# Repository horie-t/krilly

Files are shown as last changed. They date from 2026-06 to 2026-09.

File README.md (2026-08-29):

# krilly

Krilly はオムニホイールを備えたマイクロマウスです。Raspberry Pi 5 上で動作する
**ホロノミック（3輪オムニ・kiwi ドライブ）** マイクロマウスで、クラシック 16×16
マイクロマウス競技への出場を目標としています。

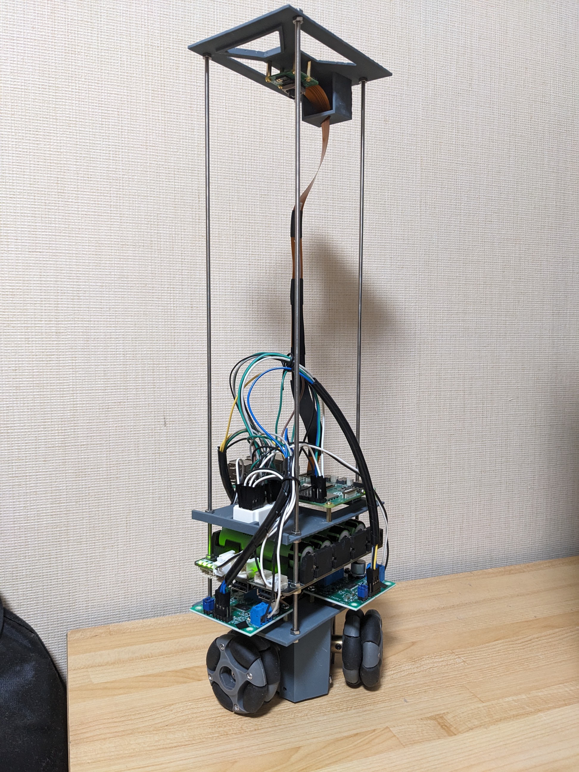
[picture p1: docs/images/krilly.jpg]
krilly


https://github.com/user-attachments/assets/f9e897da-61f6-41a8-bfa9-4333550319e2

## ハードウェア

- Raspberry Pi 5
- オムニホイール 3個（Ø48 mm・幅 25.5 mm）
- ステッピングモーター 3個（ステップ角 1.8°）＋ L6470 ドライバ 3個（SPI デイジーチェーン）
- BNO055 9軸センサー（UART モード）
- Raspberry Pi カメラモジュール V3（広角）— 下向きに取り付け、迷路の**赤い壁上面**を検知

## アーキテクチャ

下位 → 上位のレイヤ構成（`src/krilly/` を参照）:

| レイヤ | 役割 |
|---|---|
| `hal` | L6470（SPI）/ BNO055（UART）/ カメラ（picamera2） |
| `kinematics` | kiwi ドライブの正逆運動学、輪速 ⇄ ステップレート変換 |
| `motion` | ボディ速度 (vx, vy, ω) → 3輪、加減速ランプ |
| `localization` | デッドレコニング + ジャイロ姿勢 + カメラ格子補正 `[X, Y, φ]` |
| `perception` | 赤い壁上面の検出（HSV） |
| `solver` | 迷路モデル（16×16・共有エッジ）+ flood-fill + 最短経路 |
| `strategy` / `app` | 探索ラン / 最速ランの状態機械 |
| `config` | 車体・迷路の寸法（YAML） |

車体座標系・ホイール(モーター)番号・BNO055 取り付け向きの定義は
[`docs/coordinate-frames.md`](docs/coordinate-frames.md) を参照。

## 開発

```bash
python3 -m venv --system-site-packages .venv
source .venv/bin/activate
pip install -e ".[dev]"
pytest
```

Raspberry Pi 5 の実機セットアップは [`docs/setup-pi5.md`](docs/setup-pi5.md) を参照してください。
競技会場で走らせる当日の手順は [`docs/venue-checklist.md`](docs/venue-checklist.md) にあります。

進捗は [GitHub Project ボード](https://github.com/users/horie-t/projects/4) で
Milestone（M0〜M6）と Issue により管理し、コードはレビュー済みの PR を通じてマージします。

## ライセンス

MIT — [LICENSE](LICENSE) を参照。

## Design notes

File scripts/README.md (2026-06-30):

# scripts/

実機ブリングアップ・キャリブレーション・テレオペ用の単体スクリプト置き場。

各マイルストーンで追加予定:

- **M1**: `motor_spin.py`（L6470 単体/3輪回転）, `imu_stream.py`（BNO055 方位表示）, `red_detect.py`（カメラ赤検出オーバーレイ）
- **M2**: `teleop.py`（キーボード→速度指令）, `calibrate.py`（距離・L 補正）

スクリプトは `python -m` で実行できるよう、パッケージ機能を薄く呼び出す形にする。

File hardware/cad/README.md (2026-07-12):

# hardware/cad/

筐体（シャーシ）の **FreeCAD** 設計ファイル置き場。

## 方針
- 設計本体の **`*.FCStd`** をコミットする（例: `krilly-chassis.FCStd`）。
- バックアップ・一時ファイル（`*.FCStd1`, `*.FCBak`, ロックファイル）は
  `.gitignore` 済み。
- 書き出した中間データ（STL/STEP 等）は [`export/`](export/) に置く。

## 規約
- 単位は **mm**。
- 座標系は [`docs/coordinate-frames.md`](../../docs/coordinate-frames.md) に準拠
  （**+x 前 / +y 左 / +z 上**、原点は車体中心）。ホイール位置・モーター番号
  （M0 前方 / M1 後左 / M2 後右）もこの図に合わせる。
- 主要寸法（ホイール Ø48mm・幅25.5mm、中心↔接地点 `L` など）は
  `src/krilly/config/robot.yaml` と整合させる。

## 注意
- `.FCStd` はバイナリ（zip 形式）なので Git 上で差分は取りにくい。ファイルが
  大きくなる/版が増える場合は Git LFS の導入を検討する。

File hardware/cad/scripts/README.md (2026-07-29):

# hardware/cad/scripts/

`../*.FCStd` から図面などを生成するスクリプト置き場。FreeCAD の**コンソール版**で
動かすので GUI は不要。

## 実行

```bash
hardware/cad/scripts/fcrun hardware/cad/scripts/three_view.py
```

[`fcrun`](fcrun) が使える中で最も新しい FreeCAD を自動で選ぶ。優先順位:

| 順 | 対象 | 備考 |
|---|---|---|
| 1 | `$FREECAD_CMD` | 明示指定 |
| 2 | `~/opt/FreeCAD-*/AppRun` | AppImage を展開した場合 |
| 3 | `~/opt/FreeCAD*.AppImage` | **推奨**。ネイティブパスで動く |
| 4 | Windows 側 `freecadcmd.exe` | WSL interop 経由。`wslpath` で変換 |
| 5 | PATH の `freecadcmd` | apt 版。Ubuntu 24.04 は 0.21.2 止まり |

## スクリプト

- [`three_view.py`](three_view.py) — 3部品の**三面図**（第三角法・A4横・尺度 1:1）を
  [`../export/`](../export/) に出力する。対象は `PARTS`、構成は `LAYOUTS` で定義。
  TechDraw の HLR で稜線とシルエットを抽出し、SVG は自前で組んでいる。

### 図の構成（2種を併置）

平面図と真下の立面図は紙面の**横軸**を共有し、その立面図と右隣の図は**縦軸**を
共有する。この整列規則が平面図の前後向きを一意に決めてしまうので、「平面図の前方を
どちらに向けるか」は主投影図の選び方と同義になる。第一角法にしても各図の像の向きは
変わらない（配置だけが変わる）ので、どちらかを選ぶしかない。

| 出力 | 平面図の前方 | 主投影図 | 用途 |
|---|---|---|---|
| `<部品>-3view.svg` | **紙面上** | 背面図（−x 視点） | [`krilly-frame.svg`](../../docs/images/) と読み合わせる |
| `<部品>-3view-side.svg` | **紙面右** | 側面図（−y 視点） | 車両の一般配置図の慣例。正面図が入る |

```
layout "b"                          layout "side"
[ 平面図 上=+x 右=−y ]              [ 平面図 上=+y 右=+x ]
[ 背面図 上=+z 右=−y ][ 側面図 ]     [ 側面図 上=+z 右=+x ][ 正面図 ]
```

`b` は平面図の前方を上に固定した結果、整列できる立面図が −x 視点だけになるため
正面図を含められない。正面図が必要なときは `side` を使う。

用紙は**尺度 1:1 のまま収まる最小のもの**を自動で選ぶ（A4横 → A3横）。選んだ用紙は
表題欄に出る。剛性強化版の chassis（111.5 × 81.1 × 56）は平面図を上向きにする構成
だけ A4 に収まらず A3横になる。

`THREE_VIEW_PARTS` 環境変数に部品名をカンマ区切りで渡すと対象を絞れる。

```bash
THREE_VIEW_PARTS=krilly-chassis hardware/cad/scripts/fcrun hardware/cad/scripts/three_view.py
```

スクリプトは以下を assert で自己検査する。

- 各図の `right` / `up` が実際に紙面の右 / 上に落ちているか
- 平面図と真下の立面図が横軸を、立面図どうしが縦軸を共有しているか
- 第三角法になっているか（平面図は elev1 の +up 側、右隣の図は +right 側の視点か）
- 図と注記・表題欄がページ内に収まり、重なっていないか

## 注意

- **`.FCStd` を書き戻さない。** スクリプトは `recompute()` / `save()` を呼ばない。
  FCStd は FreeCAD 1.1.0 (Windows) で作られており、古い版で保存すると壊れる。
  形状は保存済みの BREP をそのまま使えば正しく読める。
- **Windows 版で実行する場合の既定値に注意。** Python の既定エンコーディングが
  **cp932**、改行が **CRLF** になる。ファイルを書くときは
  `io.open(..., encoding="utf-8", newline="\n")` と明示すること（明示しないと
  図面中の日本語が文字化けする）。
- **軸のずれがある FCStd を描くとき**は [`three_view.py`](three_view.py) の
  `MODEL_TO_BODY_DEG` に Z 回りの補正角を入れる。`krilly-chassis.FCStd` は
  2026-07-25 に `Body.Placement` の Yaw=90 で車体座標系に揃えたので現在は `0`。

## 部品の組み付け位置 (2026-07-29 剛性強化版で実測)

各部品の `Body.Placement` を下表にすると、3部品が車体座標系で正しく積み重なる。
**3部品は共通の Ø3.4×4**（chassis の `(−41.55, ±35.05)`, `(47.95, −19.95)`,
`(47.95, 35.05)`）で締結される。この4穴の一致から XY を、干渉計算から Z を決めた。

| 部品 | Position (x, y, z) | Angle | 車体座標系での占有範囲 (X / Y / Z) |
|---|---|---|---|
| `krilly-chassis` | (0, 0, 0) | **Yaw 90°** | −55.550〜55.950 / ±40.550 / 0〜56.000 |
| `krilly-middle-plate` | (**0.400**, **0**, **58.500**) | **Yaw −90°** | −55.550〜55.950 / −55.550〜40.550 / 56.000〜64.000 |
| `krilly-roof` | (**−53.550**, **−38.550**, **64.000**) | 0° | −55.550〜55.950 / ±40.550 / 61.500〜65.500 |

全体で 111.500 × 96.100 × 65.500。middle-plate だけ −y 側に 15mm 張り出す非対称形状。

検証済み（2026-07-29）:

- 4穴の一致残差 **middle-plate / roof ともに最大 0.0000 mm**。他の回転角
  (0°/90°/180°) では 16〜87mm ずれるので回転は一意に決まる
- Z は接触かつ干渉ゼロになる値。middle-plate は 58.4 で干渉 67.4 / **58.5 で 0**
  / 58.6 で 0.1mm 浮き。roof は 63.9 で干渉 1.48 / **64.0 で 0** / 64.1 で浮き
- chassis↔plate と plate↔roof は**面接触**（干渉 0・最短距離 0）、
  roof↔chassis は 5.5mm クリアランス
- **3部品の X 範囲が −55.550〜55.950 で完全一致** — 位置合わせの裏付け
- `export/*.stl` は3部品とも**配置込み**で書き出され、FCStd の bbox と一致

### chassis の向きの根拠

Ø3.5 のモーター取付穴を軸方向でグループ化すると、軸が半径方向のものが3組あり
（穴位置はすべて半径 32.68）、各組が station 角を挟む。

| 軸方向 | 穴位置の角度 | station |
|---|---|---|
| ±x | +28.3° / −28.3° | **0°** = M0 前方中央 |
| 120° | 148.3° / 91.7° | **120°** = M1 後左 |
| 60° | 268.3° / 211.7° | **240°** = M2 後右 |

`docs/coordinate-frames.md` の 0°/120°/240° に一致するので `Yaw 90` が正しい。
剛性強化版は左右対称でなくなった（Y=0 鏡像の残差 8081）ため、対称性からは
向きを決められない。モーター取付穴の軸方向で判定すること。

## 環境の確認結果 (2026-07-25)

- Ubuntu 24.04 の apt 候補は `freecad 2:0.21.2` が上限。1.1.0 は入らない。
- 公式 Linux AppImage `FreeCAD_1.1.0-Linux-x86_64-py311.AppImage`
  (820.7MB, SHA256 `ef85f171…`) は `libfuse3` のみの環境でも直接実行できた。
- AppImage と Windows 1.1.0 の出力は**バイト単位で一致**。0.21.2 の出力とも
  ジオメトリは一致した（0.21.2 で出る `App::Point` 読み込み警告は datum point
  のみの欠落で、ソリッド形状には影響しない）。

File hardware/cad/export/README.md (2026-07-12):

# hardware/cad/export/

`hardware/cad/*.FCStd` から書き出した **STL / STEP** 等の共有データ置き場。

## 方針
- ファイル名は元の部品名に合わせる（例: `krilly-chassis.stl`, `krilly-chassis.step`）。
- STL は 3D プリント用。単位は **mm**、座標系は元の FreeCAD ファイルに準拠
  （[`docs/coordinate-frames.md`](../../../docs/coordinate-frames.md): +x前 / +y左 / +z上）。
- STEP は他 CAD との受け渡し用。
- これらは `.FCStd` から**再生成できる派生物**なので、更新時は元ファイルも
  必ず一緒にコミットすること。

## 3Dプリンタ設定

対象機は ELEGOO Mars 2 での印刷の設定。ELEGOO 光造形3Dプリンター用 水洗い樹脂 UVレジンを使用。

* レイヤーの高さ: 0.05mm
* 初期層の数: 10
* 露光時間: 5s
* 初期層の露光時間: 150s
* 消灯遅延: 7s
* 初期層消灯遅延: 8s
* 初期層リフト距離: 5mm
* リフト高さ: 5mm
* 初期層上昇速度: 30mm/s
* 上昇速度: 50mm/s
* リトラクト速度: 150mm/s

## 注意
- STL/STEP はバイナリで大きくなりやすい。版が増える場合は Git LFS を検討する。

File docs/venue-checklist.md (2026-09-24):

# 会場での走行手順 (issue #78)

競技会場で走らせる当日の手順。**練習室と会場で変わるのは照明と床**で、そのどちらも
カメラの壁判定に直接効く。ここに書いてあることは全部、実機で測った結果に基づく
(根拠は CLAUDE.md の該当項目を参照)。

判断に使う数字は 2 つだけ:

- **暗さへの余力 [段]** — 起動直後の 1 行に出る。走らせる前の判断に使う
- **余裕倍率** — 一番弱い壁 ÷ しきい値。走った後の判断に使う (`survey_report`)

---

## 走らせる前

### 1. バッテリ残量を **LED で** 確かめる (電圧計では分からない)

電源は Geekworm X-UPS1 (18650 x4)。**L6470 の VS も Pi もここから取っている**
(12V/3A と 5V/3A は別々の上限)。基板の緑 LED 4 個が 25 / 50 / 75 / 100 % を示す。

**LED 4 つ (満充電) で始めること。** 効くのは**開始時の充電状態だけ**で、
5 走のセッションは弱ったパックを炙り出す負荷ケースになる。

**電圧を測っても残量は分からない。** X-UPS1 の 12V 出力は**安定化されている**ので、
電池が満充電でも半分でもほぼ 12V を返し、保てなくなったところで落ちる。
ここには以前「満充電で 12.17V」と書いてあったが、それは電池ではなく
**レギュレータの出力**を測っていた。「204 秒のセッションで 12.17 → 12.18V と
ほとんど下がらない」という測定結果自体が、安定化されている証拠になっている
(生のリチウムパックをモーターで 204 秒引いて下がらないということはない)。

**残量をソフトから読む手段は無い。** I2C の残量計は載っておらず、基板が出しているのは
LBAT (セル電圧 ≤ 3.0V で High) と PLD (外部電源断) の GPIO だけ。**LBAT は遅すぎる** —
リチウムセルの 3.0V はほぼ空で、滑りはそのずっと手前から始まる。目視の LED が指標。

弱ったパックは滑る。**L6470 のフォールトは出ず** (BEMF の脱調検出はこの速度では鈍い)、
**残差も出ない** (odometry は指令速度を積分するので、滑っても推定は理想どおり進む)。
つまり**ログを見ても分からない**。気づく手段は 2 つだけ:

1. **走らせる前に LED を見る** ← 確実
2. **異音を聞く** — 走行中に届く唯一の症状。ただし**擦れる音の原因は 4 つあって、
   パックはその 1 つに過ぎない。**

   ここには以前「#87 の測定で実際に起きた」例を挙げていたが、**あの帰属は誤りだった**:
   異音 + 進行方向に 27mm 足りない + 残差 0.4mm は事実だが、**パックは 12.17V で満充電**で、
   操作者も接触を見ていない。真の原因は**床板 (市販の競技用床) の撓みが機体底に接触**して
   いたことで、バッテリ位置を下げ・スペーサーを増やして解決した。
   **この 1 つの事象が「壁を擦った」→「電池が弱った」→「床板」と 3 回診断し直されている。**
   だから**「前にも聞いた音だ」で決めないこと。**

### 擦れる音がしたときの切り分け順

1. **LED を見る** — 4 つ点いていれば電源ではない
2. **接触を見ていたか** — 操作者が見ていて壁に触っていなければ、擦ったのではない
3. **前進と後退を聴き比べる** — `cell_move_demo --seq F4` と `--seq B4`。前進と後退は
   **同じ 2 輪を同じ輪速で回す** (W1 355 / W2 344 step/s、符号が反転するだけ) ので、
   **片方向だけ鳴るなら電源でもトルクでもなく機械**。#103 はこれで見つかった —
   ローラーのゴムが芯より長く、軸方向に押されるとホイールのプレートに擦れていた。
   机上の判定は**手でローラーを片側に寄せて回す** (= ホイールが進行方向に対して斜めの状態)
   — 固ければそれ
4. **床で切り分ける** — 黒い床で鳴って木の床で鳴らないなら、板の撓み

4 原因の対照表は CLAUDE.md の「An audible rub has had four different causes」。

### 2. 迷路の周囲 1 セルぶんを片付ける

960x720 では画角が **3.15 x 2.33 セル**あり、迷路の外に置いた赤いものが写る。
実際に、迷路の東に置いた赤い定規袋が `right:right` に 0.97 と出て、
その場所で軸角の補正が棄却された。

### 3. スタートセルに置いて、会場の照明の下で起動する

**露出と AWB は起動 0.5 秒後にロックされる。** つまり 1 回の走行は「起動した瞬間の光」に
焼き付けられる。

- 廊下で起動して運び込むのは、**別の光でロックすること**になる
- 起動の瞬間に人が機体の上に影を落とすと、1 走行まるごと狂う
- 照明が変わったら、撮り直しではなく**スクリプトの再起動**が要る

### カメラを外した・付け直したら (会場に向かう前に)

配線の変更などでカメラを付け直すと、**傾きが同じでも高さが数 mm 変わり、位置補正の校正がずれる**
(2026-09-24: ケーブルの取り回しを変えてカメラが 5-7mm 高くなった)。壁の有無は読めてしまうので
気づきにくい。四方に壁のあるセルに**定規で中央に**置いて:

```bash
python -m scripts.wall_detect --measure 5 --ev -2     # 向かい合う壁の読み (前と後、左と右) の差を見る
```

差が **2mm を超えたら** `python -m scripts.camera_fov --full-only --emit-bands --ev -2` で
`CALIBRATED_BANDS` を測り直す (手順は CLAUDE.md の該当項)。

### 4. ネットワーク (前日の試走会で SSH するとき)

スマートフォンのテザリング `AndroidAP135XL` に Pi とノート PC をつなぐ。設定と理由は
`docs/setup-pi5.md` の 8 節。

1. Pixel のテザリングをオンにする (「自動的にオフにする」は無効のまま)
2. Pi の電源を入れる。テザリングが見えれば自動でそちらにつながる (優先度 10、家の Wi-Fi は 0)
3. ノート PC も `AndroidAP135XL` につなぎ、WSL で `krilly` (`krilly.local` を Windows に引かせて SSH)
4. **つながらなければシリアル**: USB-TTL をピン 6 / 8 / 10 に挿し、PuTTY (115200、フロー制御 None) で
   ログインして次を見る

```bash
nmcli -t -f DEVICE,CONNECTION device        # wlan0:AndroidAP135XL になっているか
nmcli device wifi list                      # テザリングが見えているか (SSID の綴り)
sudo nmcli connection up AndroidAP135XL     # 手でつなぐ
hostname -I                                 # IP を読んで ssh tetsuya@<IP>
```

**USB-TTL アダプタとジャンパ線は必ず持っていく。** テザリングの IP は入れ直すたびに変わりうるので、
IP を書き留めて使い回さないこと。

### 5. 当日はボタンで走らせる (#79)

会場ではネットワーク越しに操作できないので、**前日の試走で走らせて良かったコマンドを
保存しておき、当日はボタンで走らせる**。

**前日 (試走会、SSH できるうちに)**:

```bash
sudo systemctl stop krilly-launcher          # GPIO を取り合うので止めておく
python -m scripts.speed_run --size 16 --ev -2 --white-tops --save-run-config
python -m scripts.launcher --check           # 当日走るコマンドを表示する
sudo systemctl start krilly-launcher
```

`--save-run-config` は**完走したときだけ**書く (中断したコマンドは保存されない)。
`--check` の出力で **EV と `--white-tops`** を必ず見ること — 木の床 (EV 0) の設定を
黒い床へ持ち越すと、後方の壁を見落とす (#100)。

**当日**:

| 操作 | 音 | 意味 |
|---|---|---|
| 電源を入れる | ピッ | 起動した (設定が読めないと **ピピピピピ**、そのときは走れない) |
| 1 秒押して離す | ピッ (1 秒) → ピッ ピッ ピッ ピー | 3 秒後に発進。**カウントダウンの間に手を機体の上からどける** (露出と AWB は走行プロセスの起動時にロックされる。影が落ちると 1 走行まるごと狂う) |
| カウントダウン中に押す | ピピ | 取り消し |
| 走行中に押す | ピー | 停止 (Ctrl-C と同じ経路) |
| — | ピピピッ | 完走 |
| — | ピー ピー | 中断 (安全チェックが止めた等) |
| — | ピピピピピ (繰り返し) | **走行プロセスが止まらない。VS 遮断のトグルでモータを止める** |
| 待機中に 5 秒押し続ける | ピー (1 秒) | 電源を切る (SD カードを守る) |

走行ごとの出力は `logs/run_<日時>.log` に残る。

---

## 起動直後の 1 行を読む

```
露出をロック: 32.7ms (フレーム間隔の上限) / ゲイン 3.51 (上限 16.0、残り 2.2 段)
```

**「残り N 段」が暗さへの余力**。1 段 = 明るさが半分になっても保てるという意味。
露出は 30fps 固定で頭打ちになるので、暗さに対抗しているのは実質ゲインだけ
(実測: 調光 100/30/5% で露出は 32.7ms のまま、ゲインが 2.16 → 6.21 → 10.67)。

| 残り | 判断 |
|---|---|
| **2 段以上** | 余裕。そのまま走らせる |
| **1〜2 段** | 走らせてよい。走行後に `survey_report` で余裕倍率を確認する |
| **1 段未満** | 警告が出る。下の手順へ |

### 警告が出たら: `--max-frame-duration 100` を付けて再起動する

```bash
python -m scripts.speed_run --size 16 --max-frame-duration 100
```

露出の上限が 33.3ms から伸び、**0.6 段ぶん**暗さに強くなる (実測: 露出 32.7 → 50.0ms、
ゲイン 3.51 → 2.29)。代償は 1 停止あたりの待ち時間だけ — 壁の撮影は必ず停止中に
行われる (移動 → 惰行 → 撮影) ので、走行中のブレは判定に入らない。

**100 より大きい値に意味は無い。** libcamera の AE が 50ms で露出を打ち切り、
その先はゲインに回すため、200 でも 400 でも結果は同じだった。

### それでも警告が出るなら

設定でできることは終わり。**照明が足りない。**

1. 運営に照明を上げられないか相談する
2. 上げられないなら、その照度で走ることを覚悟したうえで、まず
   **`--dry-run` か `wall_detect --measure 5`** で赤割合を見る (走らせずに確認できる)
3. 弱い壁が 0.20 を割っているようなら、走らせれば壁を倒す公算が高い

> **しきい値を下げて凌ごうとしないこと。** 進路チェックが同時に鈍り、
> 「壁検出をすり抜けたものを進路確認が拾う」という二重の防護が一重になる。
> #88 で実際にそれが起き、本物の壁 0.24 が検出 (0.25) と進路確認の両方を
> 0.01 差ですり抜けて壁を突き破った。

---

## 黒い床では `--ev -1` を付ける

**会場の床は黒い。** 視野の大半が黒いと AE が開き (ゲイン 3.3 → 7.1)、**後方の壁の帯だけが
淡くなって彩度が `s_min` を割る**。実測 (#100、市販の競技用床): back の赤割合が
**0.46 → 0.13** — しきい値 0.08 の 1.6 倍しかなく、#88 で壁を突き破ったときの 0.24 より低い。
front / left / right は 0.40-0.45 のまま変わらないので、**back だけを見ること**。

対策は **`--ev -2`** (AE の目標を 2 段下げる)。露出時間の決め打ちと違い、会場の明るさに追従する。

廊下の東端 (悪い方) での実測:

| | ゲイン | back | 帯の彩度 |
|---|---|---|---|
| EV 0 | 8.33 | **0.09** | S 42 (帯の 80% が s_min 割れ) |
| EV -1 | 3.94 | **0.17** | S 42 (69%) |
| **EV -2** | 2.00 | **0.53** | S 64 (26%) |

**EV -1 では足りない。** 西端では 0.48 まで戻るが、東端では 0.17 止まりで、
しきい値 0.08 の 2 倍しかない。-2 まで下げて初めて 0.53 (6.6 倍) になる。

front / right は EV をいくつにしても 0.42-0.46 で動かない (明度は下がるが彩度が
上がるため)。**下げて失うものは無く、back の余裕だけが戻る。**

**ただし -3 以下にはしないこと。** EV -2 の時点で back の帯の 20% が既に `v_min=40` を
割っている (EV -1 では 0%)。s_min の崖と v_min の崖の間で、-2 がその真ん中。

`--ae-constraint Highlight` は効かない (0.5 段しか戻さず back は 0.11 のまま)。

**どの辺が弱くなるかは照明の位置で決まる。** 機体の後ろの壁が天井灯を鏡面反射する
角度に来るので、この部屋では back だった。会場では別の辺かもしれないので、
**4 辺すべてを見て、一番低い辺で判断すること。**

### 手順

1. `--measure 5` を素で撮り、**4 辺の中で一番低い赤割合**を見る
2. 0.30 以上 → そのままでよい
3. 0.30 未満 → `--ev -1` で再測定 → まだ低ければ `--ev -2`
4. `--ev -2` でも戻らなければ、帯が淡いのではなく**暗すぎる**可能性がある
   (ゲインの残り段数を見る)。その場合は EV を戻して `--max-frame-duration 100`

## 黒い床では `--white-tops` も付ける (#125)

競技規定 2-1 で、**始点の区画と終点領域の区画の壁の上面は赤・白・黄のどれでもよい**。
赤しか見ないと、ゴールの境界の壁 7 枚が全部「開」と読まれ、最初にゴールへ近づいたときに
白い壁へ突っ込む。進路確認も「見えた壁で止まる」検査なので、見えない壁は止められない。

`--white-tops` で白・黄の帯も壁として読む。**`--ev -2` と組で付ける** (どちらも黒い床の設定)。

```bash
python -m scripts.speed_run --size 16 --ev -2 --white-tops
```

- **木の床では付けないこと。** EV -2 では木の床が全面「黄」と判定される (実測)
- 白・黄の帯は**壁の有無と進路確認にだけ**使い、位置補正には使わない。始点・終点では
  その軸の位置補正が効かないだけで、走行は続く
- `wall_detect --measure 5 --ev -2 --white-tops` の出力で、白・黄で拾った辺には `w` が付く
- `--white-tops` を付けると**始点の 3 壁 (前以外) を規定 2-3 から地図に書き込む** (#126)。
  始点が規定の形でない自宅の盤面 (excerpt8 系・twisty8) で黒い床を使うときは `--no-seed-start`

**試走で確かめること** (会場でしか分からない): 本物の始点・終点の上面が白か黄か、
どの辺がそうか、その明るさ。探索ランを `--save-frames` 付きで 1 本走らせれば全部撮れる。
手元の実測は**白・黄 0.446 以上に対して壁なし 0.002 以下** (しきい値 0.08)。**白の彩度は
ホワイトバランスのロックで動く** (同じ白い壁が S 6-39 のことも S 64-73 のこともあった)。会場の白が
つや消しか光沢か、床の光沢がどこに出るかで変わりうるので、`w` の付いた辺の値を見ること。

## ちらつきの確認 (水銀灯の会場では必須)

体育館の水銀灯は 100/120Hz で明滅する。露出は固定なので、フレームによって
明るさが変わりうる。**静止しているのに値が動けばそれ**:

```bash
python -m scripts.wall_detect --measure 5
```

「静止中のばらつき」の幅が 0.0mm から動くか、赤割合がフレーム間で振れるかを見る。
練習室の LED (NLEH08002E-LC) では幅 0.00 / 軸角のばらつき 0.086° で、ちらつきは無かった。
**会場でちらついたら**、露出時間を 1/50 秒の整数倍 (10ms / 20ms) に固定するのが対策
(現状そのオプションは無いので、その場では `--max-frame-duration` で露出を動かして
振れが減る点を探すことになる)。

---

## 走った後に読む

会場の迷路は形が未知なので `--truth-maze` は使えない。ラベルは走行後に確定した
地図から貼られる:

```bash
python -m scripts.search_run --size 16 --save-frames survey/venue/run
python -m scripts.survey_report survey/venue/run_labels.csv --sweep
```

**読むのは誤判定の数ではなく余裕倍率。** 学習地図で貼ったラベルでは
「毎回見落としている壁」が壁なしと記録され、誤判定 0 に見えてしまう。

| 余裕倍率 | 意味 |
|---|---|
| **5 倍前後** | 練習室と同じ。健全 |
| **2〜3 倍** | 走れるが、壁が 1 枚傾いただけで落ちうる |
| **1.5 倍以下** | 危険。#23 では誤判定 0 のまま 1.4 倍まで落ちていた |

### 余裕が足りないと分かったら

**触るのはしきい値ではなくマスク。** 保存したフレームに対して、追加の走行なしで
その場で決められる:

```bash
python -m scripts.wall_detect --batch survey/venue --weak 5      # なぜ弱いのか (色相? 彩度?)
python -m scripts.wall_detect --batch survey/venue --h2-lo 120    # 変えたらどうなるか
```

`--weak` が「取りこぼしの主因」を名指しする。`--batch` を色相や彩度を振りながら回し、
**壁側だけが上がり壁なし側が動かない**範囲を探す。壁なし側も一緒に上がるなら、
それは壁ではない何かを拾い始めている。

実際にこの手順で `h2_lo` を 140 → 125 に直した (所要 10 分、走行は確認の 1 回だけ)。
そのとき一番淡い壁は 6500K の明るい照明下で **0.046** — しきい値 0.08 を下回っており、
**見落とし = 衝突**だった。

---

## 走行中

- **ボタンで起動したときは、止めるのもボタン** (押した瞬間に SIGINT)。止まらなければ
  **VS 遮断のトグル**。SSH から走らせたときは Ctrl-C
- **止めるのは Ctrl-C。ESC は効かない** (これらのスクリプトはキー入力を読まない)。
  強制終了してモーターが回り続けたら `python -m scripts.motor_stop`
- 走行中止を自分から申し出ると、**規定 3-5 により迷路の記憶を全消去**した場合にのみ
  認められる (異常が審判に明らかな場合を除く)。赤割合 0.09 での安全停止は
  「あきらかに走行に異常」とは読まれない公算があり、そのとき探索は失われる。
  一方、規定 3-1 では記録は**最速の 1 走行**なので、最速ランが時間切れになっても
  失うのは時間だけ。**迷ったら止めずに走らせる**

---

## 参考

- 照明とカメラの実測値、赤マスクの根拠: CLAUDE.md の
  「Auto-exposure eats the brightness axis」「Wall detection is ROI-based」の項
- 校正データの取り方と読み方: CLAUDE.md「The search run *is* the survey」の項
- Pi の初期設定: [`setup-pi5.md`](setup-pi5.md)

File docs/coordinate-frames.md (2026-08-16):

# 座標系・車体・センサー・ホイールの定義

Krilly（3輪オムニ・ホロノミック）の**車体座標系**と、**ホイール/モーター番号**、
**BNO055 センサーの取り付け向き**の関係を定義する。運動学（M2 `kinematics/kiwi.py`）・
自己位置推定（M3）はすべてこの規約に従う。

車体・センサー・ホイール座標系

## 1. 車体座標系（body frame）

右手系。ROS REP-103 に準拠。

| 軸 | 向き |
|---|---|
| **+x** | 前方（ロボットの進行方向・正面） |
| **+y** | 左 |
| **+z** | 上（上面図では紙面手前） |
| **+ω** | +z 周りの回転 = **反時計回り(CCW) = 左旋回** |

- 角度はすべて **+x から反時計回り**に測る。
- 「前」は +x 方向。上面図では上を前として描く。

## 2. ホイール / モーター番号

各ホイールは**スポーク角（中心から見た位置角）**と**駆動方向角 θ（正回転で接地点が
進む向き）**を持つ。θ はスポーク角 + 90°（接線・CCW 向き）。
`config/robot.yaml` の `wheel_angles_deg` は**この駆動方向角 θ**である。

| 番号 | スポーク角(位置) | 駆動方向角 θ | 車体上の位置 |
|---|---|---|---|
| **M0 / W0** | 0° | **90°**  | 前方中央 |
| **M1 / W1** | 120° | **210°** | 後方左 |
| **M2 / W2** | 240° | **330°** | 後方右 |

- 左右対称：M1(後左) と M2(後右) は前後軸(+x)について鏡像。M0 は正面。
- **`config/robot.yaml` の `wheel_angles_deg` には「スポーク角」列 `[0, 120, 240]` を入れる**
  （運動学の式が θ にスポーク角を取るため。駆動方向 = スポーク角 + 90° = [90, 210, 330]）。
- 3輪とも正回転（正の速度）で接地点が CCW 接線方向（駆動方向）に進む → 車体は **+ω（左旋回）**。

## 3. 逆運動学プレビュー（M2 で実装）

ボディ速度 `(vx, vy, ω)` から各ホイールの周速 `v_i`（`θ_i` は**スポーク角** `[0,120,240]`）：

```
v_i = -sin(θ_i)·vx + cos(θ_i)·vy + L·ω
```
（`(-sinθ_i, cosθ_i)` は駆動方向 = スポーク角+90° の単位ベクトル）

- `L` = 中心から接地点までの距離（`config/robot.yaml` の `center_to_wheel_m`、要実測）。
- 例：純前進 `vx>0` → `v0=0, v1=-0.87vx, v2=+0.87vx`（前輪 M0 は前進に寄与せず後2輪が押す）。
- 例：純横移動 `vy>0` → `v0=+vy, v1=-0.5vy, v2=-0.5vy`。
- 例：純旋回 `ω>0` → `v0=v1=v2=L·ω`（3輪同速正回転で左旋回）。

周速 → ステッパ速度の変換は `kinematics/kiwi.py`（M2）で `wheel_speed_to_step_hz`
（L6470 Run 用の**フルステップ/s**）を用いる。

**前進と横移動では働く車輪が違う**（上の 2 例のとおり）。W0 のスポーク角はほぼ 0°、つまり
駆動方向が真横なので、W0 は事実上「横専用の車輪」で、前進中はほとんど回らない。帰結が 2 つ:

- 前進で校正した `wheel_diameter_m` は実質 W1/W2 の実効径で、W0 の径については何も
  言っていない。実測すると横だけ 1% 長かった（#76）。このため `robot.yaml` は
  `wheel_diameters_m: [d0, d1, d2]` で**輪ごとの実効径**を持てる。
- W0 のハブや軸の緩みは、前進の測定にはほぼ出ずに横移動と旋回だけを汚す（#72）。
  「前進は綺麗なのに横がばらつく」ときはまず W0 の締結を疑うこと。

## 3b. 走行時の車体の向き（旋回レス走行、M6 #76）

本機はホロノミックで、下向きカメラが 4 辺を同時に見るため、**探索・最速走行を通じて
車体の向きは迷路北に固定**し、進行方向の変更は「横移動への切り替え」で行う。

- 迷路方角 → 車体軸: **N=前(+x) / S=後(−x) / W=左(+y) / E=右(−y)**（φ=+π/2 固定）。
- `perception.wall_detect.body_walls_to_maze()` はこの固定写像に退化する。
- その場旋回のプリミティブは残してある（`--turn-in-place`）。退避路であると同時に、
  `gyro_scale_z` の校正手順（`cell_move_demo --seq L,L,L,L --camera-yaw`）が
  旋回に依存しているため。

## 4. モータードライバ（L6470）との対応

- **L6470 デバイス index i ＝ モーター Mi ＝ ホイール Wi**（i=0,1,2）。
- デイジーチェーン（`hal/l6470_chain.py`）は index0 が Pi の MOSI に最も近い配線
  （`mosi_is_index0=True`）。**M0→M1→M2 の順に SDO→次段SDI を繋ぐ**こと。
  逆順に配線した場合は `L6470Chain(..., mosi_is_index0=False)` で対応。

## 5. BNO055（9軸センサー）の取り付け向き

融合済みの絶対方位（heading/yaw）とジャイロを車体座標に一致させるため、
**センサー軸を車体軸に合わせて取り付ける**：

| BNO055 軸 | 合わせる車体軸 |
|---|---|
| X | +x（前方） |
| Y | +y（左） |
| Z | +z（上） |

- **heading(yaw) は Z 軸周り**の回転。上記取り付けなら、heading の増加方向が
  車体の **+ω（CCW=左旋回）と同符号**になる。
- ジャイロ **z 軸レート** が `+ω`（旋回角速度）に対応。M3 の姿勢推定はこれを主に使う。
- 物理的にこの向きに取り付けられない場合は、BNO055 の `AXIS_MAP_CONFIG` /
  `AXIS_MAP_SIGN` レジスタで軸を再マップする（現ドライバは未設定＝取り付けを
  合わせる前提）。

## 6. 前提・未確定事項（要確認）

- **前方/車輪角度**：✅ 実機で校正済み（#11）。`wheel_angles_deg` には**スポーク角**
  `[0,120,240]` を入れる（式が θ にスポーク角を取るため）。当初 config に駆動方向角
  `[90,210,330]` を入れていて並進が 90° ずれていたのを、`drive_demo` で
  +x=前進 / +y=左 / +ω=CCW になることを確認して修正済み。物理配置（M0 前・M1 後左・
  M2 後右）と本書の図は正しい。
- **`L`（center_to_wheel_m）**：現状 config は暫定値。M2 のキャリブレーションで確定。
- **BNO055 heading の実符号**：実機で `sys` 校正が上がった後に、左旋回で heading が
  期待どおり増減するかを確認する（必要なら符号/AXIS_MAP で調整）。

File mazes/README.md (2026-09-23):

# 迷路データ

`Maze.from_ascii` / `Maze.to_ascii` の形式 (issue #77)。北が上、行数は 2N+1。

```
+---+---+---+
|     G     |     G = ゴール (複数書ける。外接矩形がゴール領域になる)
+   +---+   +
| S |       |     S = スタート
+---+---+---+
```

- セル幅は任意 (`+-+` でも `+---+` でもよい)。`to_ascii` は 3 文字幅で書く。
- `S` / `G` を省くと スタート (0,0) ・ゴール中央 2x2 (本番設定) になる。
- ゴールは**矩形**でなければならない (`G` の外接矩形が `G` で埋まっていること)。
- **始点は北の 1 つだけ開く**のが競技の形 (規定 2-3、大会迷路 31 面すべて)。`check_maze` は
  そうでない盤面に注意を出す (#127)。`excerpt8` 系 (北と東が開) と `twisty8` (東だけ開) が該当し、
  実機で `--white-tops` を付けるときは `--no-seed-start` が要る (#126)

## 収録

| ファイル | 用途 |
|---|---|
| `practice3.txt` | 3x3 の練習迷路。実機の `search_run --size 3` と同じ形 |
| `white_goal3.txt` | 3x3、ゴールは隅の (2,2)。**ゴールの壁の上面を白/黄にして** `--white-tops` を実走で確かめる盤面 (#125、`--goal 2,2`) |
| `practice8.txt` | 8x8。**壁ちょうど 70 枚**なので手持ちで組める (#23) |
| `practice16.txt` | 16x16。解 67 セル・内壁 210 枚で、実際の大会迷路に近い密度 |

いずれも `krilly.sim.generate.random_maze` で作った合成迷路で、
`krilly.sim.check.check_maze` を通してある。

**実際の大会迷路は `contest/` にある** (2010-2024 年、31 面、#84)。
合成迷路との難易度の差もそこに測ってある — **壁の枚数を合わせても解の長さは 4 倍違う**ので、
合成迷路は本物の代わりにならない。

## 使い方

```bash
python -m scripts.maze_sim --maze mazes/practice16.txt --verbose
python -m scripts.maze_sim --maze mazes/practice8.txt --check-only --wall-budget 70
```

## 大会迷路を書き起こすとき

NTF の記録集は PDF で機械可読な形が無いので、図の画像から `scripts/maze_from_image.py`
で自動抽出する。**16x16 は壁の置き場所が 544 箇所あるので、目で写すと必ず読み違える。**
目視は「機械が出した結果が元図と合っているか」の確認だけに使う。

```bash
python -m scripts.maze_from_image <画像>... --out-dir mazes/contest
python -m scripts.maze_from_image <画像> --overlay-dir /tmp/ov   # 元図に重ねて確認
```

抽出の仕組みと検証の記録は `contest/README.md` を見ること。要点だけ:

- 壁と点線グリッドは**線に沿った平均太さ** (太さ x 連続率) で分ける。図によって
  効く手がかりが違う (太さだけ / 途切れだけ) のを 1 つの数で吸収する
- しきい値は**迷路として成立するかで自動選択**する (外周が閉じている / ゴールへ到達可能 /
  内壁が連結の上限以下)。**実際の大会迷路は必ず解ける**ので、これが強い判定器になる
- 疑わしい箇所は該当セルを拡大して目視で確認する

## 実機で組む盤面 (practice5 / excerpt8 / excerpt8_2015 / twisty8)

| ファイル | 大きさ | 壁 | 柱 | 探索手 | 最速セル | 最長直進 | **直交の補正なし** | 無壁セル | セッション |
|---|---|---|---|---|---|---|---|---|---|
| `practice5.txt` | 5×5 | 36 | 36 | 24 | 20 | 3 | **0** | 0 | 探索 45s / 最速 20s |
| `practice8.txt` | 8×8 | 71 | 80 | 16 | 16 | 7 | **2** | 1 | 探索 32s / 最速 15s |
| `excerpt8.txt` | 8×8 | 78 | 80 | 22 | 20 | 3 | **2** | 3 | 探索 42s / 最速 22s |
| `excerpt8_2015.txt` | 8×8 | **80** | 80 | **39** | 23 | 4 | **2** | 1 | 探索 55s / 最速 20.8s (実測) |
| `twisty8.txt` | 8×8 | **80** | 80 | **61** | **45** | 3 | 1 | 0 | 探索 85s / 最速 46.0s |

手持ちは**壁 80 枚・柱 85 本** (#23 で買い足し・追加製作した後)。8×8 に要る柱は
**80 本**: 格子点は `(N+1)² = 81` あるが、**ゴール 2×2 の中央には柱を立てない**。

`practice5.txt` は 5×5 を床に組んでいたときの迷路で、実機の探索ランが出力した ASCII を
そのまま起こしたもの。最速経路が実測と一致する (20 セル / 12 区間 / コスト 33.5) ので、
**シミュレーションと実測を突き合わせる基準**になる。床を組み替えたらこのファイルも直すこと。

`excerpt8.txt` は 2017 年全日本エキスパート予選の (7,8) から切り出したもの (#23 / #85)。
**いま床に組んであるのは `excerpt8_2015.txt`** — 2015 年全日本エキスパート予選の (8,1)。

`excerpt8_2015.txt` で分かることと、分からないこと (#85):

- **探索が 39 手 (excerpt8 の 1.8 倍)。** 局所の壁パターンを踏む回数がそのぶん増える
- **進行方向 (Y) の補正なしが 5 連続** — 距離だけが狂う側の最長記録。壁には当たらないが、
  止まる位置がどこまでずれるかは実機でしか分からない
- **直交の補正なしは 2 で excerpt8 と同じ。ここは組み替えても増えない** — 壁 80 枚に
  収まる切り出し 73 件すべてが 2 以下で、9×9 は柱が 99 本要り手持ち 85 本では届かない。
  8×8 が切り出せる最大なので、**2 がこの手持ちでの上限**
- 壁を**ちょうど 80 枚**使う (予備ゼロ)。到達できないセルが 3 つある (`(0,4)` `(3,1)`
  `(4,5)`、四方壁) — 窓を切ると必ず出るもので、機体は一度も入らない

実機で確かめた結果 (2 セッション、木の床・EV 0): 5 走 238s / 25 走 1102s、中断 0 回、
**28 本の最速ランがすべて同じ経路** (23 セル / 13 区間、シミュレーションどおり)、
見積もりとの差は探索 +1.4% / 最速 −0.2%、壁判定は 306 ラベルで誤り 0・一番弱い壁が
しきい値の 3.8 倍。**探索が 1.8 倍長いこの盤面では、新しい壊れ方は何も出なかった** —
出たのはこの後で手を加えた別配置の方で、6-7 セルの廊下が区間長の上限の不在を暴いた
(#85、`speed_run --max-leg-cells`)。

### `twisty8.txt` は目的が違う — 測りたいのは「サンプル数」

`twisty8.txt` だけは**難しさで選んでいない**し、**大会迷路の切り出しでもない**。
中断の発生率は 952 動作・中断 0 回で **95% 上限 0.32%/動作**までしか絞れておらず、
下げるには走るしかない。ガードが発火するのは**コーナーを含む動作**なので、
サンプル数 = 連結動作の本数で決まる:

- 探索の動作は 1 区間ずつでコーナーが無い → **0 本**。稼げるのは復帰と最速だけ
- 束ねるのは 2 区間ずつなので、**同じセル数でも区間が細かいほど連結動作が増える**

**本物の大会迷路からは、これ以上の密度は切り出せなかった。** 実迷路は長い廊下を持つ
(30 面の最長区間は中央値 11.5 セル) ので、切り出しの最良は 27 セル / 17 区間 =
384 連結動作どまり。設計すると **45 セル / 37 区間 = 864 連結動作**まで伸びる。

鍵は**ループを作らないこと**。`DEFAULT_COST` は区間 1 本を 1.62 セル分に見積もって
曲がりを嫌うので、ループのある迷路では planner が真っ直ぐな迂回路を選んでしまう。
完全迷路 (全域木) ならゴールへの道が 1 本しかなく、**曲がりを避けられない**。
内壁は 112 の置き場所に対し全域木で 48 枚 = 外周と合わせてちょうど 80 枚になる。

25 走セッションで **864 連結動作** / 所要 39 分。**1 セッションで 952 → 1816 となり
目標の 1500 を超える**。電池を考えるなら `--max-runs 13` を 2 回 (各 20 分 / 432 本)。

**組むときの注意**:

- **壁ちょうど 80 枚で予備ゼロ。** 予備が要るなら seed 178 (79 枚 / 768 本) がある
- **壁を 1 枚でも置き間違えると経路が壊れる。** 完全迷路なので、内壁を 1 枚抜くだけで
  近道ができる — 実際このレイアウトは 1 枚余計に抜くと最速経路が 45 セルから 9 セルに
  縮む。組んだら `search_run --size 8 --dry-run` と `--truth-maze mazes/twisty8.txt`
  で必ず突き合わせること
- 「直交の補正なし」は 1、無壁セルは 0 — **横流れの検証としてはやさしい**。
  狙いがサンプル数だからで、難しさを測る盤面と混同しないこと
- 本番設定 (7 分 5 走) でも最速ランは 3 本走れるので、競技として成立しない形ではない

**生成した迷路は設計された大会迷路より易しい** (このファイルの上の方に書いてある
とおり) が、ここで測りたいのは探索でも経路計画でもなく**機構の裾**なので問題にならない。

**実機で確認済み** (本番設定 7 分 5 走、木の床・EV 0):

- 探索 87.2s (50 停止) 予測 85.4s (49 停止) → **+2.1%**、最速 45.5 / 45.6 / 45.6s
  予測 46.0s → **−1.0%**、経過 366s 予測 368s、走行 4 回 (最速 3 本) も予測どおり
- **学習した地図が真の迷路と完全一致し、しかも 64 セルすべてが「4 壁とも確定」。**
  完全迷路なので探索がほぼ全域を踏む (61 手 / 訪問 54 セル) ためで、他の盤面では
  起きていない
- **6 分のセッションで連結動作 108 本** — `excerpt8_2015` の 5 走 (48 本) の 2.25 倍。
  設計の狙いどおり
- 姿勢残差は連結 108 本で中央 0.26° / 最大 0.98° / 1.0° 超ゼロ。**中央値は他の盤面
  (0.43-0.47°) より小さいのに最大は同じ** (0.93 / 0.97 / 0.98) — #107 が
  「中央値は何も言わない、裾だけの現象」と書いたとおりの形で、**裾で数えるぶんには
  盤面をまたいで足してよい**ことの傍証になる

**25 走セッションも完走した** (2317s = 38.6 分、電池 1 本):

- 見積もりとの差は 探索 +1.9% / 最速 −1.1% / 全体 −1.1%。24 本の最速ランが
  **45.4〜45.6s** (38 分を通して幅 0.2s)、地図は 64 セルとも真の迷路と一致
- **連結動作は予測どおりちょうど 864 本**。これで累計 **1986 本・中断 1 回**となり、
  発生率は上限ではなく**点推定 0.050%/動作** (95% 上限 0.24%) になった
- **裾が初めて見えた**: 1.0° を超えた読みが **13 本 (1.5%)**、最大 **−1.79°**
  (ガードの 2.5° の 72%)。108 本のときは 1.0° 超がゼロだったが、1.5% なら 108 本で
  1.7 本の期待値なので**分布が変わった証拠にはならない** — 標本が 8 倍になっただけ。
  裾を測るには本数が要る、という #107 の教訓がそのまま出ている
  (数は目視で数えたので ±1。次からはログを `| tee` でファイルに残すこと)

### 「直交の補正なし」がこの表の主役

進行方向と直交する向きに壁が無いセルでは横方向の位置補正が入らず、そのぶん横に流れる。
廊下の余裕は片側 21.4mm しかないので、続くと壁に当たる。**進行方向の欠落は距離が狂う
だけで壁には当たらない**ので、危険度がまるで違う。

**5×5 はここが 0** — つまり横方向の補正が毎セル入っていた。これまで一度も試していない。

### 切り出し方

```bash
python -m scripts.maze_excerpt --size 8 --maze mazes/contest/*.txt \
    --wall-budget 80 --post-budget 85 --min-search 18 --min-cells 16 --out mazes/excerpt8.txt

# 2 面目。**1 位が床にあるとは限らない** — 直交の補正なしが同点 (2) なので、
# 2 位は探索の長さで選んでいる。--rank で順位を指定する
python -m scripts.maze_excerpt --size 8 --maze mazes/contest/*.txt \
    --wall-budget 80 --min-search 18 --rank 2 --out mazes/excerpt8_2015.txt

# 中断の発生率を測るための盤面。**切り出しではなく生成から選ぶ** — 本物の大会迷路は
# 長い廊下を持つので、曲がりの密度は設計した方が上がる (384 -> 864 連結動作)
python -m scripts.maze_excerpt --size 8 --generate 2400 \
    --wall-budget 80 --sort exposure --min-cells 24 --out mazes/twisty8.txt

# 選ばれたのは seed 1770。ファイルだけならこれで再現できる
python -c "from krilly.sim.generate import random_maze; \
    print(random_maze(8, seed=1770, loop_ratio=0.04).to_ascii())"
```

`--min-search` は要る。直交の補正なしだけで並べると、**ゴールのすぐ隣を 6 手動くだけ**の
迷路が上位に来て探索の検証にならない (指標 1 つに最適化した典型的な失敗)。

### ゴールは競技の形にすること

窓を切り出すと、**元の迷路では普通のセルだった場所をゴールと宣言する**ことになるので、
そのままでは内側に壁が残り入口も 4 つになる。競技のゴールは **2×2 が 1 つの開いた区画で
入口は 1 つ** (大会迷路 31 面のうち 23 面が入口 1 つ、残りも 2-3 つ)。
`sim.generate.open_goal_region` / `sim.excerpt.goal_variants` が直す。

**ゴール中央には柱が存在しない。** NTF クラシック競技規定 9:
「迷路の終点となる4区画内には壁や柱は存在しない。」

「壁の付かない柱」ではなく「柱そのものが無い」ので、**必要な柱の本数が 1 本減る**
(8×8 は 81 本ではなく 80 本)。`Maze.to_ascii` はそこに `+` を描かない — 描くと、
この図を見て組む人が立ててしまうため。実測でも大会迷路 31 面のうち 28 面で
「壁の付かない柱」がここ 1 本だけだった (`posts_without_wall` の `ignore_goal_center`)。

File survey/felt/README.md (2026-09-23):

# 白・黄の壁上面の判定用フレーム (#125)

すべて同じ条件で撮った: **黒い競技用床 (自宅)・`--ev -2`・960×720**。機体の上面は
つや消しの緑のフェルトで覆ってあり、カメラには H 98 / S 255 で写る。撮ったのは 2026-09-23 で、
場所は同じ 1 セル (壁は柱に差し込む)。各セットは `wall_detect --measure 5 --save-prefix` の
5 フレーム (`_01`〜`_05`)。

| セット | 壁 | 機体 | 備考 |
|---|---|---|---|
| `on_4w` | 赤 4 枚 | 中央 | フェルトを調整する**前**、支柱は金属のまま。BACK の既定 ROI の 22 % がフェルト |
| `on_0w` | なし (柱だけ) | 中央 | 同上 |
| `on_4w-2` | 赤 4 枚 | 中央 | フェルトを調整し (BACK 既定 ROI の 7 %)、支柱を緑のテープで覆った後 |
| `wy_a` | front/right = 白、back/left = 黄 | 中央 | |
| `wy_b` | front/right = 黄、back/left = 白 | 中央 | |
| `on_0w-2` | なし (柱だけ) | 中央 | |
| `on_0w-2s` | なし (柱だけ) | 右へ ~15 mm | 床の光沢が RIGHT の探索範囲に入る。**明るさだけの判定はここで 0.245 と読んだ** |
| `wy_a_s` | front/right = 白の 2 枚だけ | 右へ ~13 mm | 白い帯と床の光沢が同じ ROI に並ぶ |

ゲインは 2.35〜3.25 (白い壁があると AE が絞って下がる)。床の光沢は画像の右側
(天井灯の映り込み) に出て、その彩度は `on_0w` で S 46〜57、`on_0w-2` / `on_0w-2s` で S 11〜30
だった — 同じ場所・同じゲインで動いたので、白と彩度で分けることはできない。

`tests/data/white_tops/` にはこのうち 5 枚 (`wy_a` / `wy_b` / `on_0w-2s` / `on_4w-2` / `wy_a_s`
の各 `_03`) を回帰テスト用に置いてある。

3x3 の実走 (`mazes/white_goal3.txt`) のフレームは `survey/white_goal/` にある。そちらでは
白い壁が S 64-73 (青みがかった白) と写り、当時の `white_s_max = 60` を超えて (1,2) で
白い壁に突っ込んだ。

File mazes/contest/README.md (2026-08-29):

# 全日本マイクロマウス大会の迷路 (書き起こし)

大会記録集の図から `scripts/maze_from_image.py` で自動抽出したもの (issue #84)。
2010〜2024 年、**31 面**すべて異なる迷路。

```bash
# 再抽出 (図を追加したとき)
python -m scripts.maze_from_image <画像>... --out-dir mazes/contest

# 通しセッションを回す
python -m scripts.maze_sim --maze mazes/contest/*.txt
```

## なぜ本物が要るのか (生成迷路との差を実測した)

**壁の密度を合わせても、生成した迷路は本物の 4 分の 1 の難しさしかない。**
31 面ずつ比べた中央値:

| | 内壁 | 解 | 探索 | 最速ラン | 走行回数 |
|---|---|---|---|---|---|
| **実際の大会迷路** | **214** | **59 歩** | **90 手** | **77s** | **3 回** |
| 生成 `loop_ratio=0.10` | 193 | 16 歩 | 21 手 | 25s | 5 回 |
| 生成 `loop_ratio=0.35` | 147 | 14 歩 | 17 手 | 19s | 5 回 |
| 生成 `loop_ratio=0.00` | 225 | 82 歩 | 82 手 | 91s | 2 回 |

内壁 214 枚の本物の解が 59 歩なのに対し、内壁 193 枚の生成迷路は 16 歩。
**難しさを作っているのは壁の枚数ではなく配置**で、そこは乱数では再現できない。

一方**局所の指標は生成迷路とよく一致する** (X 補正なしのセル 27% 対 28%、
Y 28% 対 30%、四辺とも壁なしのセル 4 個対 5 個)。つまり:

- カメラ判定・1 セルの制御 (#85) は生成迷路でもある程度代表できる
- 探索・経路計画・持ち時間の予算は**本物でしか試せない**

## 分かったこと

持ち時間はクラシック競技規定 3-6 の **7 分**・5 走 (規定 3-4 の始点 2 秒停止込み)。

- **31 面中 14 面で最速ランが 1 本も走れない。** ゴールには着くが、そこから
  復帰 + 最速を始める時間が残らない
- 走行 5 回を消化できたのは **1 面だけ** (2016 フレッシュマン予選)
- 走行回数の中央値は 5 回中 **2 回**
- 探索 中央値 140s / 最大 366s、最速ラン 中央値 72s
- 探索の手数は 32〜236 手、解は 24〜121 歩と幅が大きい

持ち時間別の内訳 (最速ランを走れない面数):

| 持ち時間 | 走れない面 | 走行回数の中央値 |
|---|---|---|
| 10 分 (別競技の規定) | 2/31 | 3 |
| **7 分 (クラシック規定)** | **14/31** | **2** |
| 5 分 (規定 3-6 の例外) | 27/31 | 1 |

**当初 10 分で評価していたのは誤り** (10 分はマイクロマウス競技=旧ハーフサイズの規定)。
3 分の差で結論が「ほぼ走れる」から「半分近く走れない」に変わる。

## 読み取りの検証

`scripts/maze_from_image.py` は迷路として成立する読み取りしか採らない
(外周が閉じている / スタートからゴールへ到達可能 / 内壁が連結の上限以下)。
そのうえで個別に確かめたもの:

| 迷路 | 確認したこと |
|---|---|
| `2013_japan_exp_q` | 図の下部に**公式解「西回り 52歩29折、54歩29折 南回り 52歩25折、54歩23折」**が記載されている。抽出した迷路の最短経路が **52 歩 29 折**、折れ最小が **52 歩 25 折**で一致 |
| `2013_japan_exp_q` | 裸の柱が 27 本あるのは読み落としではない (柱 (1,9) を 10 倍に拡大し、四方が点線のみであることを確認) |
| `2010_japan_freash_fin` | 裸の柱 2 本目 (11,3) を同様に拡大して確認 |
| `2020_japan` | 四方を壁で囲まれたセル (11,6) を拡大して確認。**囲まれたセルは大会迷路に実在する** |

**「裸の柱はゴール中央の 1 本だけ」は 31 面中 28 面で成り立つが、規則ではない。**
上の 2 面が反例で、抽出ツールもこれを誤りとして弾かず「要確認」に回すだけにしてある。

ゴールは全面が中央 2x2。図によっては `G` が 1 個しか書かれていないので、
1 セルだけ検出したときは中央 2x2 に補正している (2013 年の公式解との一致で裏を取った)。

## まだ確認していないこと

- **全 544 箇所の壁を 1 枚ずつ元図と突き合わせたわけではない。** 上の検証は
  「迷路として成立する」「公式解と一致する (1 面)」「疑わしい箇所を拡大して確認 (3 箇所)」まで
- 記録集に公式解が載っている図が他にもあれば、同じ照合を増やせる

## 書き起こしが壊れている迷路 (要 再確認)

ゴールの形と柱の条件で機械的に洗ったところ、3 面に問題が見つかった (#23)。
**元図を確認せずにデータを書き換えるのは筋が悪い**ので、ここに記録して直せる人に渡す。

| 迷路 | 症状 | 見立て |
|---|---|---|
| `2016_japan_freash_q` | ゴール 2×2 が縦横とも壁で仕切られている (内部の壁 4 枚) | 実在しない形。ゴール周辺の壁を拾いすぎている |
| `2013_japan_exp_q` | 壁の付かない柱が **27 本** | 壁を大量に取りこぼしている。要 全面再抽出 |
| `2010_japan_freash_fin` | 壁の付かない柱が 1 本余分 (11,3) | 壁 1 枚の取りこぼし |

`2016_japan_freash_q` は `tests/test_sim.py` の `KNOWN_BAD_TRANSCRIPTIONS` に入れてあり、
健全性チェックが**落ちること**をテストしている (直したら除外リストから外す)。

判定の根拠: 正しい迷路では**壁の付かない柱はゴール中央の 1 本だけ**になる。
31 面のうち 28 面がそうで、外れた 3 面がここに挙げたもの。

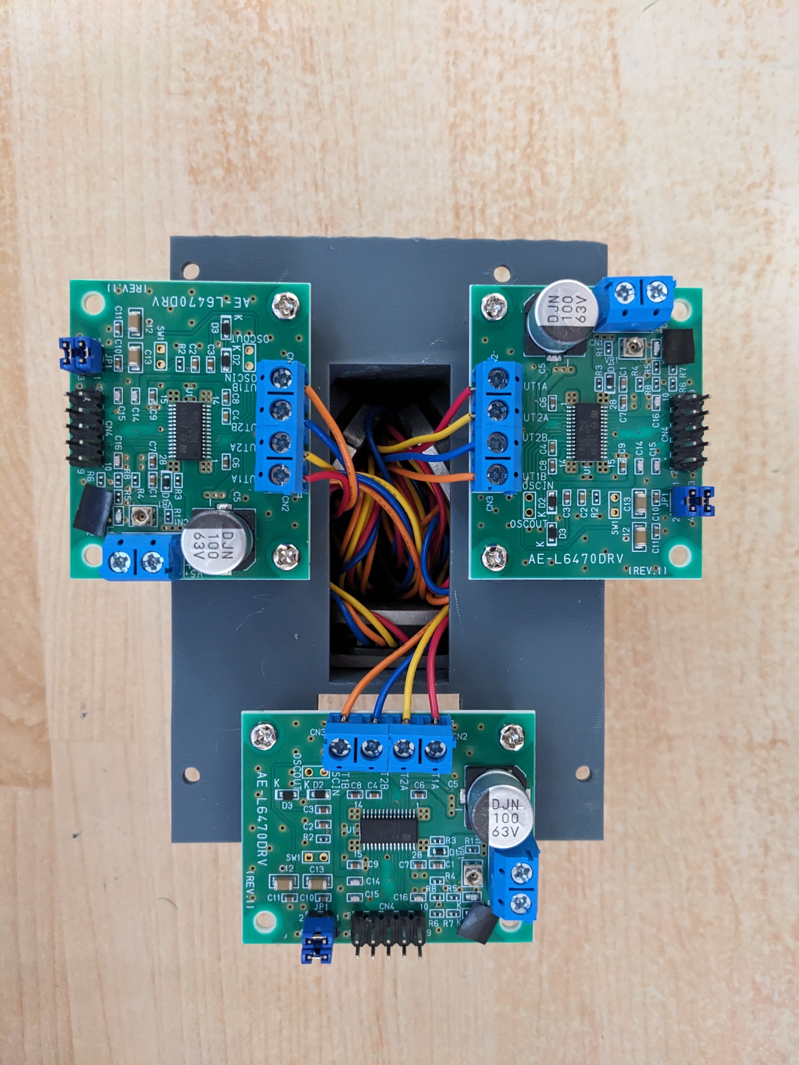
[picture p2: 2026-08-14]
docs/images/motor-driver-module-connection.jpg

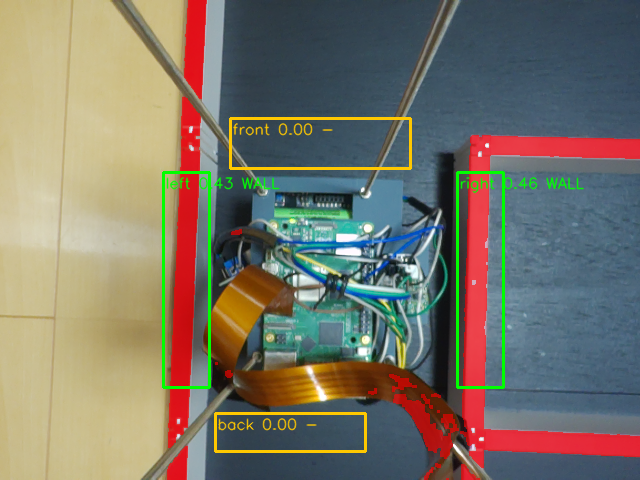
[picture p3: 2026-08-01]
walls.png

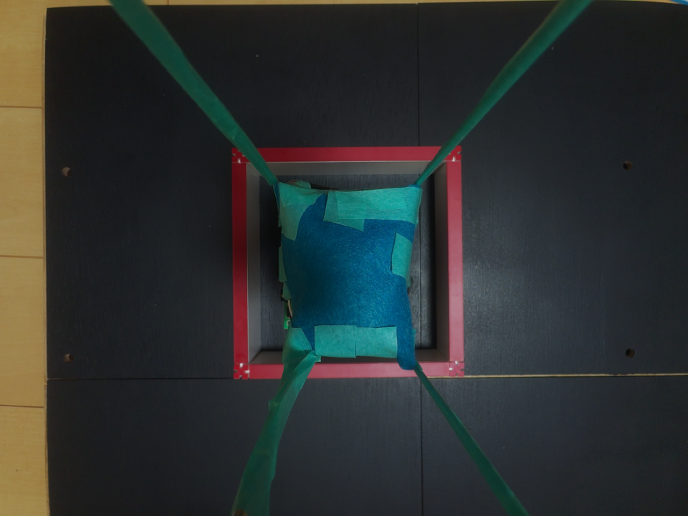
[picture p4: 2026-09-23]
survey/felt/on_4w-2_05.png

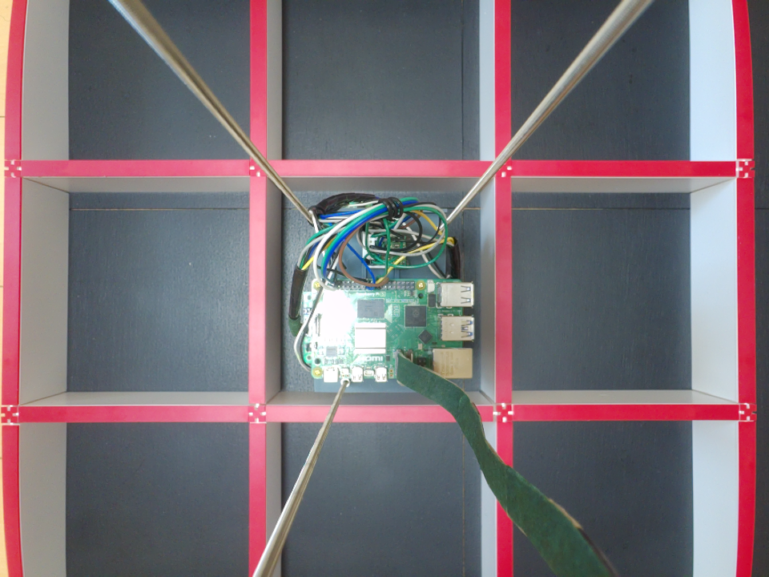
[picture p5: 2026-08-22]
fov_cal/full_fov.png

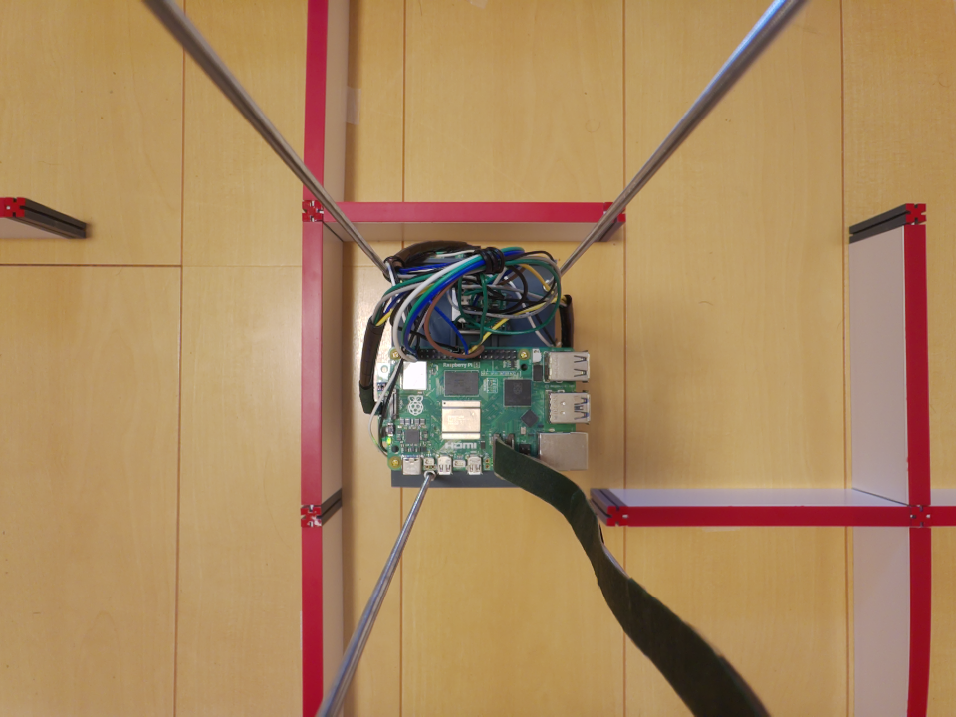
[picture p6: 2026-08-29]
survey/L_2700_100/shot02_c54_N.png

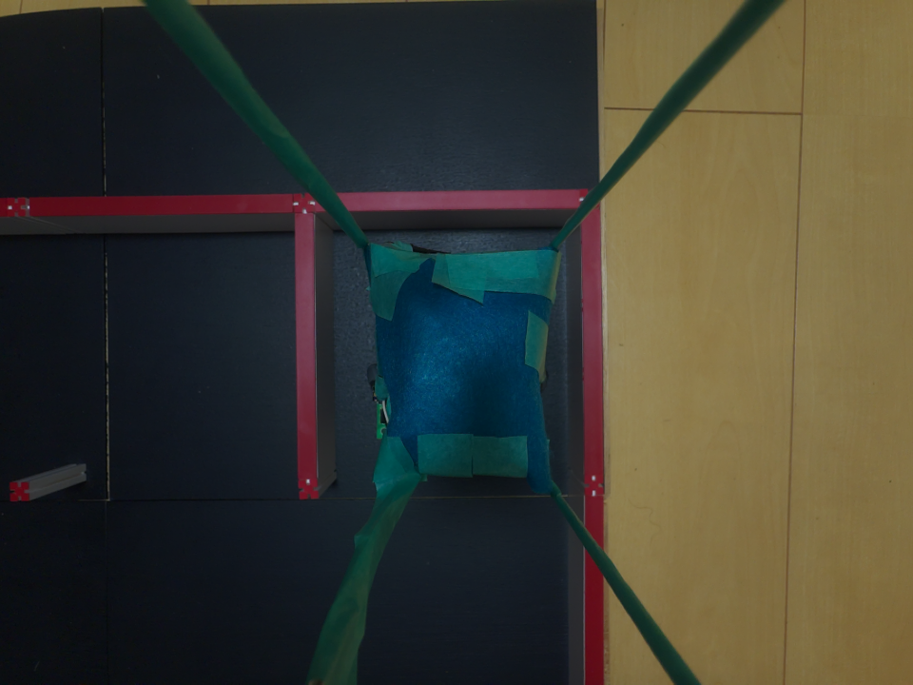
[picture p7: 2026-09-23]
survey/white_start2/run_024.png

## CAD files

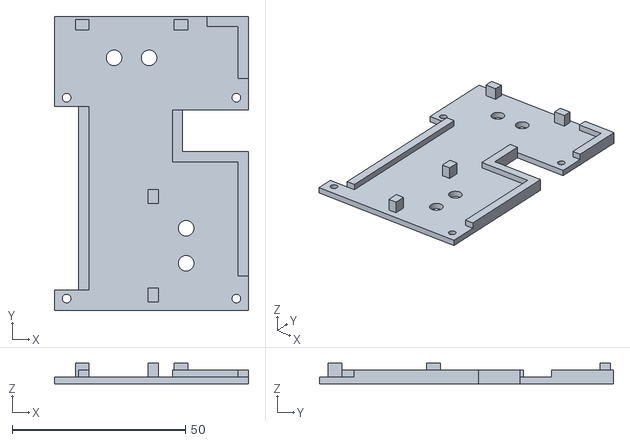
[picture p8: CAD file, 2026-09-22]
hardware/cad/export/krilly-circuit-plate-Body.stl
56.0 x 85.0 x 6.00

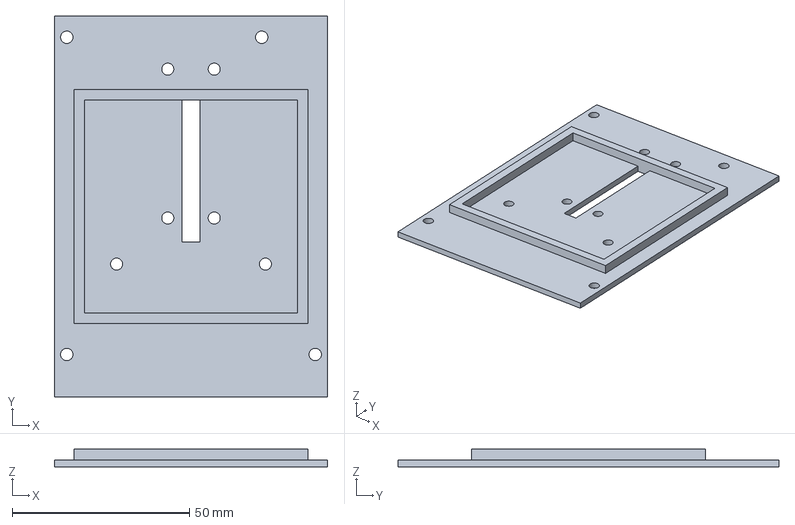
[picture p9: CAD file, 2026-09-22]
hardware/cad/krilly-motor-driver-plate.FCStd
77.1 x 107.5 x 5.00 mm

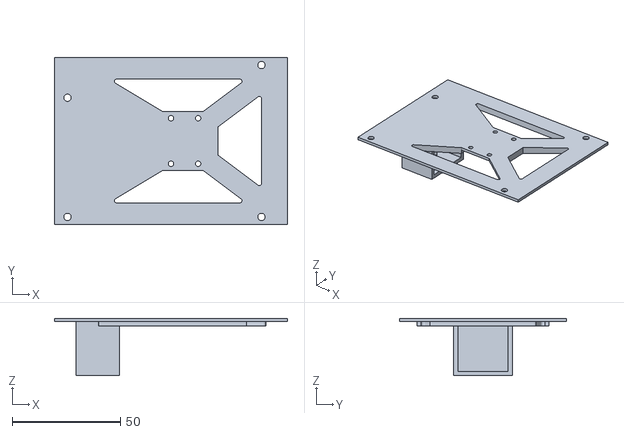
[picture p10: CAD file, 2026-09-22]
hardware/cad/export/krilly-roof-Body.stl
107.5 x 77.1 x 26.5

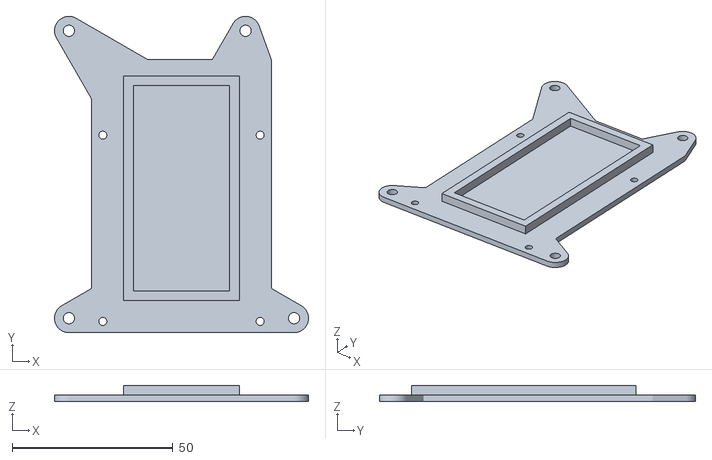
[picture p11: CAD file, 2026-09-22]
hardware/cad/export/krilly-middle-plate-Body.stl
79.1 x 98.5 x 5.00

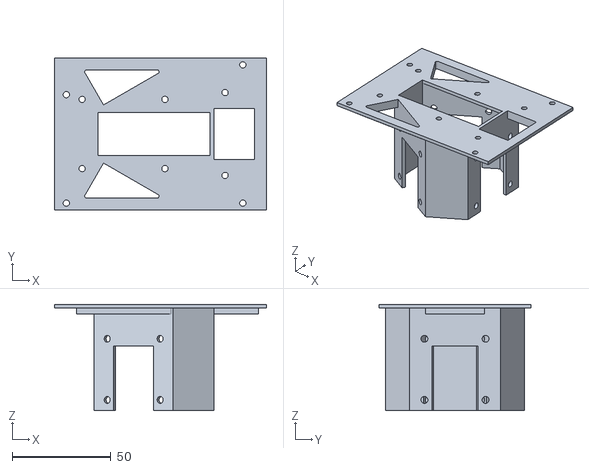
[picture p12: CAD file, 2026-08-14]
hardware/cad/export/krilly-chassis-Body.stl
107.5 x 77.1 x 54.0

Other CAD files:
hardware/cad/krilly-roof.FCStd
hardware/cad/krilly-middle-plate.FCStd
hardware/cad/export/krilly-motor-driver-plate-Body.stl
hardware/cad/krilly-circuit-plate.FCStd
hardware/cad/krilly-chassis.FCStd

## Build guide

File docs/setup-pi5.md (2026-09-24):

# Raspberry Pi 5 セットアップ手順

Krilly を実機(Raspberry Pi 5 / Raspberry Pi OS)で動かすための初期設定。
Pi 5 は GPIO/SPI/I2C/カメラが新しい **RP1 I/O チップ**経由になっている点に注意。

## 1. OS と基本パッケージ

Raspberry Pi OS (Bookworm 以降) を前提とする。

```bash
sudo apt update && sudo apt full-upgrade
# picamera2 / lgpio は OS に同梱・apt 提供
sudo apt install -y python3-picamera2 python3-lgpio python3-opencv i2c-tools
```

> **GPIO ライブラリ**: Pi 5 では `RPi.GPIO` は動作しない(SoC レジスタ直叩きのため)。
> `lgpio` / `gpiozero` を使う。SPI(`spidev`)・I2C のバス自体はカーネルドライバ経由で正常。

## 2. SPI を有効化 (L6470 ×3 デイジーチェーン)

```bash
sudo raspi-config   # Interface Options -> SPI -> Enable
# もしくは /boot/firmware/config.txt に:
#   dtparam=spi=on
```

- 接続: SPI0、**CS 1本**でデイジーチェーン。SPI mode 3 (CPOL=1/CPHA=1)、MSB-first、~5MHz。
- 初期化時に各ドライバの STATUS を読み、UVLO/OCD 等の電源投入フラグをクリアすること。

## 3. I2C を有効化 (BNO055)

BNO055 モジュール(AE-BNO055-BO)は出荷時 **I2C モード(アドレス 0x28)** で、
ジャンパ変更なしに SDA/SCL 配線だけで使える。

```bash
sudo raspi-config   # Interface Options -> I2C -> Enable
# /boot/firmware/config.txt:
#   dtparam=i2c_arm=on
```

- 配線: VIN->3.3V(pin1), GND, SDA->GPIO2(pin3), SCL->GPIO3(pin5)。**電源は3.3V**
  (基板のレベル変換が VIN 電位になるため、5V 給電すると信号も5Vになり Pi を痛める)。
- 確認: `i2cdetect -y 1` で `0x28` が見えること。
- **クロックストレッチ**: 旧 Pi(1〜4) の Broadcom BSC はクロックストレッチのバグが
  あり BNO055 と相性が悪かったが、**Pi 5 は RP1(DesignWare)の I2C に変わり正しく扱える**。
  実機で **100kHz(既定)のまま BNO055 が安定動作することを確認済み**。低速化は不要。
  万一不安定な場合のみ `dtparam=i2c_arm_baudrate=10000` を追加する。
- Python からは `smbus2` で読む (`hal/imu.py`)。ドライバ側でも転送をリトライする。

## 4. カメラ (Camera Module V3 wide)

```bash
# Bookworm では libcamera/picamera2 が標準。接続後に確認:
rpicam-hello --list-cameras
```

- 取得は **picamera2** の `capture_array()` → NumPy → OpenCV。
- `cv2.VideoCapture` は libcamera スタックでは使えない。
- 下向き運用: 低解像度・露出/AWB をロックして赤壁上面を安定検出。

## 5. gpiochip 番号の確認

カーネル更新で RP1 の gpiochip 番号が変わることがある(`gpiochip4` ↔ `gpiochip0`)。

```bash
pinctl 2>/dev/null || gpioinfo | head
```

ライブラリが `gpiochip` を開けないエラーを出す場合は番号のズレを疑う。

## 6. Krilly のインストール

```bash
cd ~/repos/krilly
python3 -m venv --system-site-packages .venv   # picamera2/lgpio を OS から流用
source .venv/bin/activate
pip install -e ".[dev]"
pytest          # M0 スモークテスト
```

> 非Pi の開発マシンでは hardware-only 依存(`spidev`/`lgpio`/`picamera2`)は
> `platform_machine == 'aarch64'` 条件でスキップされ、ロジックの単体テストは実行可能。

## 7. ボタンとブザーで起動する (#79)

会場ではネットワーク越しに操作できないので、電源を入れたらボタン待ちになるようにする。

**配線** (BCM 番号。変えるなら `config/run.yaml` の `button_gpio` / `buzzer_gpio`):

| 部品 | 配線 | 備考 |
|---|---|---|
| タクトスイッチ | GPIO17 (物理ピン 11) と GND の間 | 内部プルアップで読むので抵抗は要らない |
| 圧電ブザー | GPIO18 (物理ピン 12) と GND の間 | 発振回路内蔵 (active) なら `buzzer_passive: false` |
| 非常停止トグル | **VS (モータ電源) の線を直接切る** | ソフトを通らない。SIGKILL で L6470 が回り続けたときの最後の手段 |

SPI0 (GPIO 7-11) と I2C1 (GPIO 2, 3) は使用中なので避ける。

**GND は物理ピン 6 / 9 / 14 / 20 / 25 / 30 / 34 / 39。隣の 22 は GPIO25 で GND ではない。**
共通の GND 線を 20 のつもりで 22 に挿すと、ボタンは押しても反応せず (GPIO17 が Low に
落ちない)、ブザー側の GPIO18 は Low を出しているのに High と読める。
`python -m scripts.launcher --beep-test` がボタンの状態も表示するので、配線を触ったら通すこと。

**入れ方**:

```bash
sudo cp deploy/krilly-launcher.service /etc/systemd/system/   # パスとユーザは環境に合わせる
sudo systemctl daemon-reload
sudo systemctl enable --now krilly-launcher
journalctl -u krilly-launcher -f
```

電源断 (5 秒長押し) は `sudo -n systemctl poweroff` を呼ぶ。Raspberry Pi OS の既定ユーザは
パスワード無しの sudo が通るが、そうでなければ sudoers に
`<ユーザ> ALL=(root) NOPASSWD: /usr/bin/systemctl poweroff` を足す。

**開発中は止めておく**: SSH から `speed_run` などを走らせるとき、ランチャが動いていると
ボタンの GPIO を取り合い、ボタンに触れると走行が起動しうる
(`sudo systemctl stop krilly-launcher`)。

## 8. 会場用のネットワークと、つながらないときの復旧 (シリアルコンソール)

会場ではスマートフォン (Pixel 4a) のテザリングに Pi とノート PC の両方をつなぎ、SSH する。
Pi がテザリングにつながらなかったときのために、**USB シリアルでログインできる**ようにしておく。

### テザリングの接続設定

```bash
sudo nmtui      # 「接続の編集」→ 追加 → Wi-Fi。SSID と パスワードを入れる (履歴に残さないため nmtui で)
sudo nmcli connection modify AndroidAP135XL connection.autoconnect-priority 10
```

- **SSID は `AndroidAP135XL`** (「AP」が入る)。最初 `Android135XL` で登録して、テザリングが見えているのに
  つながらなかった。**スマートフォンの画面の表記ではなく、`nmcli device wifi list` に出る名前を使うこと**
- 優先度 10 は家の Wi-Fi (0) より高いので、**テザリングが見えればそちら、見えなければ家の Wi-Fi** を
  自動で選ぶ。再起動しても、テザリングを切っても、そのとおりに切り替わることを確認済み
- Pixel 側: 「アクセスポイントを自動的にオフにする」は無効、セキュリティは WPA2-Personal
- テザリングの IP は DHCP で、**入れ直すたびに変わりうる** (確認時は 10.208.167.50)。名前 `krilly.local` で
  つなぐ (下の「ノート PC から」)

### シリアルコンソール (GPIO14/15)

USB-C を USB Ethernet にする方法 (`rpi-usb-gadget`) は**この機体では使わない**。Pi 5 の USB-C は電源の
入り口でもあり、機体は GPIO / ポゴピンから X-UPS1 の 5V で動いているので、ノート PC をつなぐと 5V が
二重になる。USB-TTL (3.3V) アダプタで UART につなげば、GND・TX・RX だけなので電源はぶつからず、
**ネットワークの設定が壊れていてもログインできる**。

```bash
sudo raspi-config           # Interface Options → Serial Port → ログインシェル: はい / ハードウェア: はい
echo "dtparam=uart0_console" | sudo tee -a /boot/firmware/config.txt
sudo reboot
ls -l /dev/serial0          # -> ttyAMA0 になっていれば OK
```

**Pi 5 では `raspi-config` だけでは足りない。** コンソールが基板上の 3 ピンのデバッグ用コネクタ
(`ttyAMA10`) に出るだけで、GPIO14/15 (`ttyAMA0`) にはログイン画面が出ない。`dtparam=uart0_console` が
コンソールをピン 6 / 8 / 10 に移す (`/boot/firmware/overlays/README`、2712 のみ)。

| USB-TTL アダプタ | Pi (物理ピン) |
|---|---|
| GND | 6 (GND) |
| RX | 8 (GPIO14 = TXD) |
| TX | 10 (GPIO15 = RXD) |

**VCC はつながない。** Windows では PuTTY を使う (WSL2 から COM ポートは直接扱えない):

| 画面 | 項目 | 値 |
|---|---|---|
| Session | Connection type / Serial line / Speed | Serial / デバイス マネージャーの COM 番号 / **115200** |
| Connection → Serial | Data bits / Stop bits / Parity / **Flow control** | 8 / 1 / None / **None** (既定の XON/XOFF から変える) |
| Window → Translation | Remote character set | UTF-8 |

Open した直後は真っ黒のことがある。**Enter を 1 回押す**と `krilly login:` が出る。何も出なければ TX/RX の
入れ違い、文字化けは速度、表示は出るのに入力できなければフロー制御を疑う。

### ノート PC (Windows + WSL2) から

Windows は `krilly.local` を引ける (mDNS) が、WSL2 (NAT) からは引けないので、WSL2 から Windows に
引かせる。WSL の `~/.bashrc`:

```bash
krilly() {
    local ip
    ip=$(powershell.exe -NoProfile -c "(Resolve-DnsName -Name krilly.local -Type A).IPAddress" \
         | tr -d '\r' | head -1)
    ssh tetsuya@"${ip:?krilly.local が引けない (シリアルで hostname -I を確認)}" "$@"
}
```

`powershell.exe` が「**実行形式エラー**」で動かないときは、WSL の interop の登録が消えている
(systemd を有効にした WSL でよく起きる):

```bash
sudo sh -c 'echo ":WSLInterop:M::MZ::/init:PF" > /usr/lib/binfmt.d/WSLInterop.conf'
sudo systemctl restart systemd-binfmt       # それでもだめなら PowerShell で wsl --shutdown
```

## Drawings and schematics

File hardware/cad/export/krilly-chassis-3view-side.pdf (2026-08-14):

注記

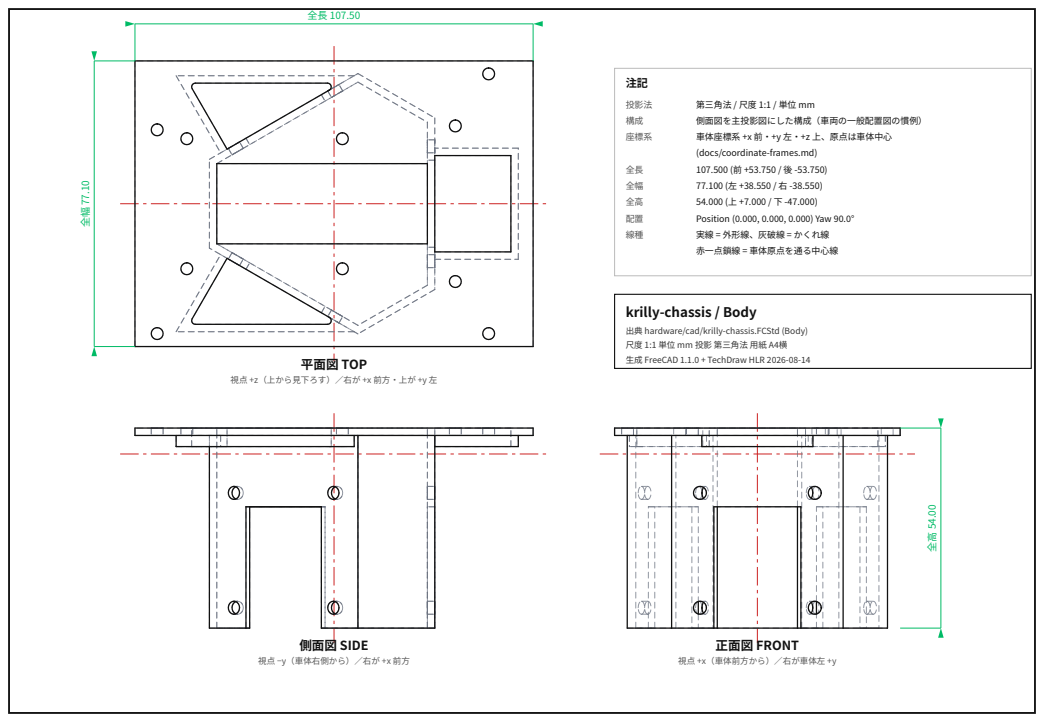
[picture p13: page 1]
平⾯図 TOP; 側⾯図 SIDE; 正⾯図 FRONT; 投影法; 第三角法 / 尺度 1:1 / 単位 mm; 側⾯図を主投影図にした構成（車両の⼀般配置図の慣例）; 座標系; 車体座標系 +x 前・+y 左・+z 上、原点は車体中⼼; Position (., ., .) Yaw .°; 実線 = 外形線、灰破線 = かくれ線; 赤⼀点鎖線 = 車体原点を通る中⼼線

(docs/coordinate-frames.md)

krilly-chassis / Body
出典 hardware/cad/krilly-chassis.FCStd (Body)
尺度 1:1 単位 mm 投影 第三角法 ⽤紙 A横
⽣成 FreeCAD .. + TechDraw HLR --

視点 +z（上から⾒下ろす）∕右が +x 前⽅・上が +y 左

視点 −y（車体右側から）∕右が +x 前⽅

視点 +x（車体前⽅から）∕右が車体左 +y

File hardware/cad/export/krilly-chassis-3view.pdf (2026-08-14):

注記

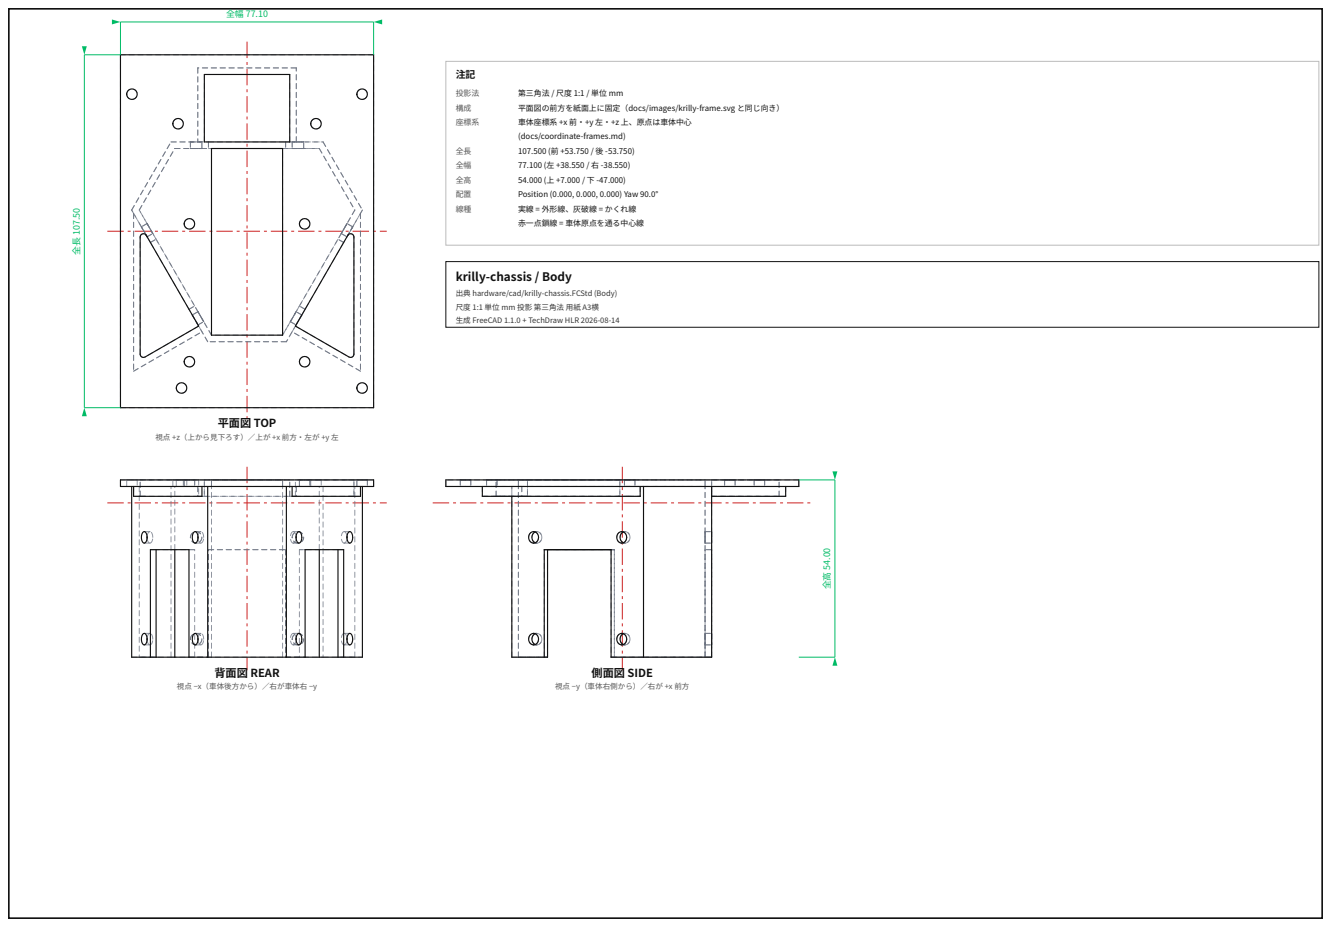
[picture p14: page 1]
平⾯図 TOP; 背⾯図 REAR; 側⾯図 SIDE; 投影法; 第三角法 / 尺度 1:1 / 単位 mm; 平⾯図の前⽅を紙⾯上に固定（docs/images/krilly-frame.svg と同じ向き）; 座標系; 車体座標系 +x 前・+y 左・+z 上、原点は車体中⼼; Position (., ., .) Yaw .°; 実線 = 外形線、灰破線 = かくれ線; 赤⼀点鎖線 = 車体原点を通る中⼼線

(docs/coordinate-frames.md)

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

視点 +z（上から⾒下ろす）∕上が +x 前⽅・左が +y 左

視点 −x（車体後⽅から）∕右が車体右 −y

視点 −y（車体右側から）∕右が +x 前⽅

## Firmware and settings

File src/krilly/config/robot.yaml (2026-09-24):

# 車体の物理パラメータ (SI 単位: m)
# 出典: ハードウェア構成
#   オムニホイール 直径48mm / 幅25.5mm / 3個
#   ステッピングモーター ステップ角1.8° (=200 step/rev)

# 実効径 (公称48mm)。実機で校正済み (#11, scripts/calibrate --straight)。
# #17 で迷路上を 2 セル走らせて実測との比で 2 段階に修正 (旧筐体・嵌め合わせ床):
#   0.04629 -> 0.04732 (実測 368mm / オドメトリ 360mm, +2.2%)
#   0.04732 -> 0.04771 (実測 363mm / オドメトリ 360mm, +0.8%)
# 筐体改修 (モータドライバを上へ、ホイール配置変更) 後に再測定。4 セル直進 720mm 指令
# に対する床のテープ印からの実測を 3 回:
#   径 0.04771 -> 707mm (実効径 0.04685)   ※初回のみ外れ値
#   径 0.04685 -> 727mm (実効径 0.04731)
#   径 0.04708 -> 724mm (実効径 0.04734)
# 後 2 回が一致するので平均 0.04732 を採用。カメラ実測 (cell_pose の前後差分) は
# 定規と 2.4mm 以内で一致するので、以後は定規なしで検証できる。
# 迷路のピッチは実測で正確に 180mm (柱 6 本 = 5 セルで 900mm) なので、迷路側ではなく
# 機体側の変化。
wheel_diameter_m: 0.04732
wheel_count: 3

# 車輪ごとの実効径 [m] (W0, W1, W2)。省略すると全輪 wheel_diameter_m。
#
# **前進と横移動では駆動する車輪が違う。** 逆運動学の係数は
#   前進 (vx): W0 +0.026 / W1 -0.879 / W2 +0.853
#   横移動(vy): W0 +1.000 / W1 -0.477 / W2 -0.522
# なので、上の wheel_diameter_m (4 セル前進の定規実測で校正) は**実質 W1/W2 の実効径**で、
# W0 の径は一度も測られていなかった (#76)。
#
# 1x15 の通路で機体の置き方だけ変えて同じ距離を比べた実測 (指令 720mm):
#   前進   720 / 723mm (F4 x2)、1435/1440mm (F8)  -> +0.02%
#   横移動 718 / 731 / 728 / 734 / 725mm (H4 x5)  -> **+1.00%**
# 横だけ 1% 長い。W0 の実効周長が +1.5% だとすると横 +1.00% / 前進 +0.00% となり、
# 両方の実測を同時に説明できる (W0 の vx 係数が 0.026 と小さいので前進には出ない)。
#
# 2026-09-24、**黒い競技用床**で測り直した (3x3、v 0.30、EV -2、--align --camera-pose、
# 単独の 2 セル、各 3 回、カメラで前後の位置の差を測る):
#   横移動 東 +6.0/+7.2/+6.0mm、西 +4.8/+4.8/+4.8mm (720 ではなく 360mm 指令) -> **+1.55%**
#   前進   +0.0/+3.6/+0.0mm                                                     -> +0.3%
# 方位と横ずれを保持した閉ループでは、横の伸びは W0 の周長の誤差の 0.662 倍
# (前進には 0.001 倍しか出ない)。+1.55% を消すには W0 をさらに +2.34%:
# 0.04803 -> 0.04915 (W1/W2 より計 +3.9%)。木の床で合わせた +1.5% では足りない
# ので、**床で W0 の実効径が変わる**可能性が高い。本番の黒い床に合わせてある
# (木の床では横移動が 1% ほど手前で止まるかもしれない — 測っていない)。
wheel_diameters_m: [0.04915, 0.04732, 0.04732]
steps_per_rev: 200

# マイクロステップ分割数 (L6470 STEP_MODE)。1/16 を初期値とする。
microstep: 16

# 中心から各輪の接地点までの距離 L [m]。
# 実機で校正済み (#11, scripts/calibrate --rotate)。
# #17: wheel_diameter_m を上げたのに合わせて同率で上げた (0.04595 -> 0.04737)。
# --rotate は当時の径を前提に L を出しているため、径だけ変えると L/径 の比が崩れて
# 旋回の指令角速度がずれる。同率で上げれば比が保たれ、旋回の挙動は変わらない
# (旋回はジャイロで閉じているので精度自体は径・L に依存しない)。
#
# 筐体改修でホイール配置が変わったため、径とは独立に**実測**した (0.04737 -> 0.04507)。
# 測り方 (定規不要): 定常回転させ、指令 omega とジャイロ実測 omega の比から
#   L_actual = L_cfg * omega_cmd / omega_actual
# 指令は各輪へ v_i = L_cfg*omega を出すので、実際の回転は L_actual に反比例する。
# 4 回測定 0.04495/0.04530/0.04508/0.04495、ばらつき 0.4%。
# **ハードウェアが変わったときは同率スケールではなく測り直すこと。**
center_to_wheel_m: 0.04507

# 各輪の「スポーク角」(車輪位置の角度) [deg]。120°対称配置。
# 運動学の式 v_i = -sin(theta_i)*vx + cos(theta_i)*vy + L*omega は、theta_i に
# このスポーク角を入れると正しく動く (駆動方向 = スポーク角 + 90°)。
# M0=前(spoke 0°, 駆動+y) / M1=後左(120°) / M2=後右(240°)。docs/coordinate-frames.md 参照。
# 実機で校正済み (#11): drive_demo で +x=前進 / +y=左 / +omega=CCW を確認。
#
# 筐体改修後、前進指令だけで機体が斜めに進む (クラブ走行) ようになったため、三輪の
# 取付角の実測値へ補正した。4 セル直進 720mm で機体は東へ 22mm (定規: 西壁との隙間
# 24->46mm、カメラ: 左右オフセット -21.2mm) 動いた -> atan(21.6/720) = 1.72°。
# スポーク角が一様に delta 回っていると、前進指令 vx に対し vy = vx*sin(delta) の
# 横成分が出る (方位はジャイロで保持されるので「斜めに平行移動」になる)。
# config を実測の取付角に合わせれば打ち消せる。
#
# #21 で -1.72 は行き過ぎと判明し、-0.42 へ戻した (差 +1.30°)。M5 の測り方は
# **置いたときの傾きと走行中の回転を差し引いていなかった**のが誤りで、機体側の
# クラブとカメラから見た横流れを同一視していた。正しくは
#   横流れ = 720mm * sin(置いた傾き + 走行中の回転/2 + クラブ角)
# で、置いた傾きは axis_yaw の before、走行中の回転はカメラの前後差から取れる。
# **測り直すときは必ず --camera-yaw を併用して置き方の傾きを分離すること。**
#
# ただし #21 の測定は W0 のハブ (六角) が緩んだ状態で取っていた (#72)。W0 は
# スポーク角がほぼ 0° = 駆動方向が真横なので、その緩みは横流れの測定を直接汚す。
# ネジを締めてから測り直すとクラブ角は -1.58 / -1.53° (幅 0.05°、修理前は幅 1.2°)
# と初めて再現した。
#
# 3 つの config で各 2 本ずつ測った (すべて 4 セル直進):
#   config -0.42 -> クラブ角 -1.583 / -1.537° (平均 -1.560)
#   config -1.20 -> クラブ角 -0.410 / -0.425° (平均 -0.418)
#   config -1.49 -> クラブ角 -0.586 / +0.137° (平均 -0.224)  <- 採用
# 前 2 点の傾きは -1.46 (理論の -1 とは合わない。三輪の取付角の誤差が一様な回転では
# なく輪ごとに違うためと思われる)。外挿した -1.49 で **-0.22 ± 0.17°** となり、
# ゼロと区別がつかない。ここで打ち止め。
#
# **1 本あたりの測定雑音は σ≈0.24° あるので、これ以上は追い込めない。**
# 内訳は軸角 (5 フレーム中央値で σ=0.20°) と、走行中の回転 Δ の 1/2。上の 3 組で
# 2 本の幅が 0.046 / 0.015 / 0.723° と暴れているとおり、幅が小さく出るのは運であって
# 精度ではない。**校正は必ず 2 本以上の平均で決め、幅が 0.3° 以内でも喜ばないこと。**
#
# なお「スポーク角を変えると前進のスケールも動く」効果は理屈の上では存在するが
# (config を変えると W1/W2 の指令速度が 0.8% 非対称に変わり、推定器は同じ行列で
# 戻すので気づかない。最大 0.8% x 720mm = 5.8mm)、実測は単調でなく
# (前後誤差が config -0.42/-1.20/-1.49 で +2 / -10.6 / +1.8mm)、支持されない。
# -1.49 では 4 セルの実移動が定規で 720 / 723mm (指令 720mm) なので
# wheel_diameter_m は据え置き。
wheel_angles_deg: [-1.49, 118.51, 238.51]

# BNO055 ジャイロ z のスケール補正 (読み値 * この値 = 実際の角速度)。1.0 で補正なし。
# カメラの軸角実測 (perception/axis_yaw) と比べて校正する:
#   scripts/cell_move_demo --seq L,L,L,L --camera-yaw
#   新しい値 = 現在の値 * (実測した真の回転量 / 推定した回転量)
# #17: 0.984 (360°で +1.61% 過大)
# IMU の取付が緩んでいたのを締め直したら +3.3% 過大になった (360°で -6.1°、3回測定の
# ばらつき 0.3%)。傾いていると読み値が cos(傾き) 倍に減り、スケール誤差を隠していた
# (3.3% x cos10° ≒ 1.7% が以前の測定値と一致する)。**IMU を触ったら必ず測り直す**。
gyro_scale_z: 0.970

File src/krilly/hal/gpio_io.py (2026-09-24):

"""機体単体で起動・停止するためのボタンとブザー (issue #79)。

本番の会場ではネットワーク越しに操作できないので、**ボタン 1 個 + ブザー**で走らせる
(ボタンの意味は状態で変わる: :mod:`krilly.app.launcher`)。

- ボタン: タクトスイッチを GPIO と GND の間に入れ、**内部プルアップ**で読む
  (押すと 0 = ``active_low``)。外付けの抵抗は要らない
- ブザー: ``passive`` (圧電素子そのもの) なら PWM で鳴らす。``active`` (発振回路内蔵)
  なら H/L だけで鳴る。**passive で鳴らしても active は鳴る** (断続音になるだけ) が、
  逆は鳴らない (カチッと言うだけ) ので、既定は passive

Pi 5 の GPIO は RP1 経由なので ``RPi.GPIO`` は動かない。``lgpio`` を使う
(``docs/setup-pi5.md``)。他の HAL と同じく ``gpio=`` にフェイクを挿せば実機なしで
テストでき、省略したときだけ ``lgpio`` を import してチップを開く。
"""

from __future__ import annotations

#: 既定のピン (BCM 番号)。SPI0 (GPIO 7-11) と I2C1 (GPIO 2, 3) を避けた空きピン。
#: 実機で配線したピンに合わせて ``run.yaml`` で変えられる。
DEFAULT_BUTTON_GPIO = 17        # 物理ピン 11
DEFAULT_BUZZER_GPIO = 18        # 物理ピン 12
DEFAULT_CHIP = 0                # Pi 5 の RP1 (カーネルによっては gpiochip4 と同じもの)
#: passive ブザーを鳴らす周波数 [Hz]。圧電素子の共振 (2-4 kHz) の辺りが一番大きい。
DEFAULT_TONE_HZ = 2700


def open_gpio(chip: int = DEFAULT_CHIP):
    """``lgpio`` を import してチップを開き、``(lgpio モジュール, ハンドル)`` を返す。"""
    import lgpio

    return lgpio, lgpio.gpiochip_open(chip)


class _Pin:
    """``lgpio`` のモジュールとハンドルの組 (注入されたものか、自分で開いたものか)。"""

    def __init__(self, gpio, chip: int) -> None:
        if gpio is None:
            self.lg, self.handle = open_gpio(chip)
            self._owned = True
        else:
            self.lg, self.handle = gpio
            self._owned = False

    def close(self) -> None:
        if self._owned:
            self.lg.gpiochip_close(self.handle)
            self._owned = False


class Button:
    """タクトスイッチ 1 個。``is_pressed()`` は瞬間値 (チャタリング除去は呼び出し側)。"""

    def __init__(self, pin: int = DEFAULT_BUTTON_GPIO, gpio=None,
                 chip: int = DEFAULT_CHIP, active_low: bool = True) -> None:
        self.pin = pin
        self.active_low = active_low
        self._io = _Pin(gpio, chip)
        flags = self._io.lg.SET_PULL_UP if active_low else self._io.lg.SET_PULL_DOWN
        self._io.lg.gpio_claim_input(self._io.handle, pin, flags)

    def is_pressed(self) -> bool:
        level = self._io.lg.gpio_read(self._io.handle, self.pin)
        return (level == 0) if self.active_low else (level == 1)

    def close(self) -> None:
        try:
            self._io.lg.gpio_free(self._io.handle, self.pin)
        finally:
            self._io.close()


class Buzzer:
    """圧電ブザー。``on()`` / ``off()`` だけを持ち、鳴らし方の型は呼び出し側が決める。"""

    def __init__(self, pin: int = DEFAULT_BUZZER_GPIO, gpio=None,
                 chip: int = DEFAULT_CHIP, passive: bool = True,
                 tone_hz: int = DEFAULT_TONE_HZ) -> None:
        self.pin = pin
        self.passive = passive
        self.tone_hz = tone_hz
        # lgpio は **PWM が動いていないときに止めると例外** ('bad PWM micros') を出す
        # (実機で確認: 鳴らす前の off も、2 回続けた off も落ちる)。動いているかを自分で持つ
        self._pwm_on = False
        self._io = _Pin(gpio, chip)
        self._io.lg.gpio_claim_output(self._io.handle, pin, 0)

    def on(self) -> None:
        if self.passive:
            self._io.lg.tx_pwm(self._io.handle, self.pin, self.tone_hz, 50)
            self._pwm_on = True
        else:
            self._io.lg.gpio_write(self._io.handle, self.pin, 1)

    def off(self) -> None:
        if self._pwm_on:
            self._io.lg.tx_pwm(self._io.handle, self.pin, 0, 0)
            self._pwm_on = False
        self._io.lg.gpio_write(self._io.handle, self.pin, 0)

    def close(self) -> None:
        try:
            self.off()
            self._io.lg.gpio_free(self._io.handle, self.pin)
        finally:
            self._io.close()

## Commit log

2026-06-30 M0: プロジェクト基盤の足場 (scaffold/deps/config/docs)
    - レイヤ構成に沿った src/krilly パッケージ雛形 (hal/kinematics/motion/
    localization/perception/solver/strategy/app/config)
    - pyproject.toml: 依存定義 (numpy, pyyaml, pyserial, opencv, BNO055;
    hardware-only は aarch64 条件で分離) + dev: pytest
    - config: robot.yaml / maze.yaml と型付きローダ (RobotConfig/MazeConfig)
    - ロギング基盤 (logging_config)
    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
    [robot.yaml]
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2026-06-30 M1: L6470 単体駆動ブリングアップ (1台ずつ)
    故障基板の切り分けのため、デイジーチェーンの前に L6470 を1台ずつ動作確認する。
    - hal/l6470.py: 単体ドライバ制御クラス + 純粋な変換関数
    - SPI mode3・バイト毎CSトグル (spidev, 遅延import)
    - Run/Move/SoftStop/HardStop/SoftHiZ/HardHiZ/Reset
    - Set/GetParam, GetStatus (初期化時に電源投入フラグをクリア)
    - steps/s・steps/s^2 ⇄ レジスタ変換 (tick=250ns データシート係数)
    - L6470Profile: 保守的な初期トルク/速度 (STEP_MODE 1/16)
    - scripts/motor_spin.py: 1台ずつ回転/移動を確認するCLI (bus/device/向き/速度/時間)
    - t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
    [l6470.py, motor_spin.py]
2026-07-04 motor_spin: STATUSデコーダ修正 + 通信不可検出
    - STATUS のビット位置を修正 (UVLO=bit9, OCD=bit12; 従来は誤位置)
    - 全0/全1 は SPI 応答なしとして明示検出・警告
    - 初期化STATUSが異常ならモーター指令を送らず中止する安全ガード
    Refs #5
    [motor_spin.py]
2026-07-04 motor_spin: 初回読み出しの UVLO は正常フラグと注記
    - _decode_status に first_read 引数を追加。リセット後の初回 GetStatus では
    UVLO は電源投入時に必ずラッチされ読み出しでクリアされる正常フラグのため、
    「初回読み出しなら電源投入時の正常フラグ」と表示して誤解を防ぐ。
    - 終了時 STATUS を1回の読み出しに修正 (hex とデコードを同一値に)。
    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
    [motor_spin.py]
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2026-07-05 imu_stream: Ctrl+C クリーン終了 + Pi5はクロックストレッチ問題なしを反映
    - imu_stream: 無限ループ時の KeyboardInterrupt を捕捉しトレースバックなしで終了。
    終了方法(Ctrl+C / --duration)を起動時にログ表示。
    - docs/setup-pi5.md: Pi 5 は RP1(DesignWare) I2C でクロックストレッチを正しく
    扱えるため 100kHz 既定で BNO055 安定動作を確認、低速化は不要と修正。
    - hal/imu.py: 同上をモジュール docstring に反映。
    Refs #6
    [imu.py, imu_stream.py]
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2026-07-20 docs: CLAUDE.md を現状のコードベースに合わせて更新
    スタブ記述を実態に置換:
    - コマンド(setup / pytest 単体実行 / 各ブリングアップスクリプト)
    - ハードウェア・ツールチェーン(Pi5, L6470/SPI, BNO055/I2C, カメラ/picamera2)
    - レイヤ・アーキテクチャ(hal/kinematics/perception/config ...)
    - 規約とハマりどころ(テスト可能HALパターン, 座標系, L6470単位, picamera2チャンネル順, STATUS解釈)
    - コントリビュートワークフロー(Issue単位のブランチ/PR, オーナーレビュー後マージ, コメントは日本語)
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2026-07-20 M2: 運動学の車輪角度を実機に合わせて校正 (#11)
    drive_demo の実機確認で、並進(vx,vy)の向きが 90° ずれていた。原因は
    wheel_angles_deg に駆動方向角[90,210,330]を入れていたが、運動学の式
    v_i=-sinθ·vx+cosθ·vy は θ にスポーク角を取る(駆動方向=θ+90)ため。
    物理配置(M0前/M1後左/M2後右)と図・回転(ω)は正しく、config値と記述のみ誤り。
    - config/robot.yaml: wheel_angles_deg をスポーク角 [0,120,240] に修正 + コメント明確化
    - kinematics/kiwi.py: docstring を「スポーク角、駆動方向=θ+90」に修正
    - docs/coordinate-frames.md: config はスポーク角[0,120,240]であ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
    [robot.yaml]
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2026-07-20 M2: steps↔距離・L の実機キャリブレーションツール
    - scripts/calibrate.py: L6470 Move で既知量だけ動かし、実測値から補正後の
    config 値を算出。
    - --straight D : 前進 D[m] 指令 → 実測距離から wheel_diameter_m を補正
    - --rotate T : その場回転 T[回転] 指令 → 実測回転から center_to_wheel_m(L) を補正
    - 補正計算は純関数 (corrected_wheel_diameter / corrected_center_to_wheel)
    - wheel_moves_for_body: ボディ変位→各輪(向き,マイクロステップ)
    - 値は自動書き込みせず表示 (ユーザーが robot.yaml を更新)
    - tests/test_calibrate.py: 補正式と Move 変換 (前進/回転) を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
    [calibrate.py]
2026-07-20 M2: 運動学パラメータを実測キャリブレーション値に更新 (#11)
    scripts/calibrate による実測結果を反映:
    - wheel_diameter_m: 0.048 -> 0.04629 (実効径, 公称48mm)
    - center_to_wheel_m(L): 0.050 -> 0.04595
    コメントも「校正済み」に更新。
    Refs #11
    [robot.yaml]
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2026-07-20 M3: ジャイロ融合 (相補フィルタ) で姿勢φを補正
    - localization/estimator.py:
    - _integrate() を切り出し、積分処理を共通化
    - update_with_gyro(): 並進は車輪、回転dφは**ジャイロ**から取る
    (スリップに強い。φ誤差の蓄積を抑制)
    - update_with_gyro_rate(): 各輪速度[m/s]とジャイロ角速度[rad/s]をdtで積分
    - correct_heading(): 絶対方位へ weight で緩やかに引き込む(相補の低域側,
    最短角で処理) — BNO055融合headingや#14の迷路整列方位で使う
    - _wrap_angle(): 角度正規化
    - scripts/heading_demo.py: 旋回を走らせ「オドメトリのみφ」と「ジャイロ融合φ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
    [heading_demo.py]
2026-07-20 M3: カメラ格子スナップによる位置補正
    - localization/grid.py: snap_to_grid() と GridCorrector
    - 180mmピッチの既知グリッド線 (offset + n*pitch) へ X/Y をスナップ
    - apply_x/apply_y: max_error で誤検出をガードしつつ推定位置を補正
    - from_maze(MazeConfig) で cell_pitch から生成
    - localization/estimator.py: correct_x / correct_y / correct_position を追加
    (相補フィルタの位置版。格子スナップの受け皿)
    - localization/__init__: GridCorrector, snap_to_grid をエクスポート
    - tests/test_grid.py: スナップ(offset/負値), 位置補正, tolerance ガードを検証
    - 計 107 passed
    注: カメラ画素→地面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
2026-07-25 hardware: 3部品を車体座標系に揃え、三面図の生成を追加する
    これまで chassis のモデル軸は車体座標系に対し Z 回りに 90° ずれ、プレート2枚は
    原点が部品の隅にあった。hardware/cad/README.md と export/README.md の「座標系は
    元の FreeCAD ファイルに準拠 (+x前/+y左/+z上)」という記述が実態と合っていなかった
    ので、Body.Placement で3部品を車体座標系に揃えた。
    - chassis: Yaw 90°。取付部3箇所が 0°/120°/240° = M0(前)/M1(後左)/M2(後右) になる
    - middle-plate: Position (-50.468, -38.500, 17.000)
    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
    [krilly-chassis-Body.stl, krilly-chassis.FCStd, krilly-middle-plate-Body.stl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]
2026-07-29 hardware: 筐体を剛性強化版に更新し、三面図を再生成する
    プレートの強度不足で筐体全体が撓む問題への対応として3部品を再設計した。
    併せて `Body.Placement` を車体座標系に再設定し、三面図を作り直した。
    外形の変化（車体座標系）:
    - chassis: 77.170 x 70.269 x 49.000 -> 111.500 x 81.100 x 56.000
    体積 18754 -> 35797（ほぼ倍）
    - middle-plate: Z 8.000（-y 側に 15mm 張り出す非対称形状、幅 96.100）
    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
    [krilly-chassis-Body.stl, krilly-chassis.FCStd, krilly-middle-plate-Body.stl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]
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2026-07-30 docs: CLAUDE.md を M2/M3/M4 の実装内容に追随
    - 【誤り修正】wheel_angles_deg は駆動方向角ではなく**スポーク角**[0,120,240]。
    駆動方向は θ+90。誤って駆動方向角を入れると並進だけ90°回る(#11の症状)。
    - 迷路グリッド(東+x/北+y, Direction)と車体座標の区別、body_walls_to_maze を明記
    - 融合方針: 並進=車輪 / 姿勢=ジャイロ / 絶対補正=correct_heading・GridCorrector
    - config は実測校正値 (公称に戻さない・テストでハードコードしない)
    - アーキテクチャ: motion(VelocityDriver)/localization(DeadReckoning,GridCorrector)/
    solver(Maze 共有エッジ) を stub から実装済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
2026-08-01 M4: 実機校正 — ジャイロスケール補正とカメラによる方位実測
    実機で 90°ターンの残差を追い込むうちに、原因が 2 つに分かれることが分かったので
    それぞれ対処する (#17)。
    1. 終了しきい値: 実機の残差はほぼ許容値そのものになるため、angle_tol_rad を
    1.0° -> 0.3°、pos_tol_m を 3mm -> 1.5mm に詰める。ただし許容値を詰めると
    エンベロープ終端の指令が静止摩擦を下回るので、主軸に下限速度 (min_v /
    min_omega) を入れる。`下限 * dt <= 2 * 許容値` なら 1 tick で許容帯を
    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
    [robot.yaml]
2026-08-01 M4: 迷路床で距離校正 — wheel_diameter_m / center_to_wheel_m
    CellMotion の 1セル前進を実機 (迷路 3x3) で測ったところ、推定は 360.0mm と言うのに
    物理的には 2 セルで 7mm 行き過ぎていた。オドメトリは指令速度の積分なので、これは
    制御ではなく径のスケール誤差 (#17)。
    実測方法: --seq F,F を走らせ、最終セル中心からのズレを「前後の壁との隙間の差 ÷ 2」
    で測り、2 セル分の実距離 (361mm — 嵌め合わせ床の 2つめのセルが 1mm 大きい) に足して
    実距離を出し、オドメトリ値との比を径に掛ける。2 段で 7mm -> 2mm -> 1mm 以下に収束。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
    [robot.yaml]
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2026-08-01 fix: 壁判定が右壁を見落とす問題を修正 (ROI ずれ + 白飛び)
    実機の探索ラン (#18) で東壁を「壁なし」と誤判定して衝突した。原因は 2 つ (#56)。
    1. ROI が赤帯からずれていた。東壁の帯は x≈464-490 なのに right ROI は x=438-484 で
    半分が黒い床。back も帯 y≈425-445 に対し ROI y=398-436 で切れていた。#16 の校正
    写真は手置きで、閉ループ (#17, ±1mm) の停止位置とは十数px ずれていた。
    実測した帯を CALIBRATED_BANDS に記録し、ROI をそこに合わせる
    (right x 438->457, back y 398->413)。テストで ROI が帯を含むことを検証する。
    2. 右壁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
    [wall_detect.py]
2026-08-01 fix: 壁判定を帯探索に変え、全セル調査で校正する
    前コミットで ROI としきい値を直したが、実機の全セル調査 (9セル×4向き=160ラベル)
    で 31/80 の壁を見落としていた。原因は色ではなく**幾何**だった (#56)。
    - 機体の実際のセル内位置は最大 25mm (≒40px) ずれる。前進は 2セルで 1mm 以下だが、
    その場回転が毎回わずかに滑り、CellMotion の位置保持はオドメトリなので滑りが
    見えない。40 回転で 5-25mm 積み上がっていた (推定は「セル中央 0.1mm」のまま)。
    20mm ずれると幅 26px の帯は幅 46px の ROI からほぼ外れる。
    - 固定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
    [wall_detect.py, wall_survey.py]
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2026-08-02 fix: IMU 締め直し後に gyro_scale_z を再校正 (0.984 -> 0.968)
    IMU の取付が緩んでいた。締め直したところ、ジャイロ z の過大が +1.6% から +3.3% に
    変わった (360°の物理誤差 -6.1°、1.5°/ターン)。これが「旋回の度に通路の向きから傾き、
    壁に衝突する」症状の原因。
    傾いていると読み値が cos(傾き) 倍に減るため、傾きはスケール誤差を**隠す**方向に働く
    (3.3% x cos10° ≒ 1.7% で、以前の測定値と一致する)。つまり締め直した今の 0.968 の方が
    正しい。3 回測定してばらつき 0.3% を確認してから採用した (ガタが残っていれば
    ばらつ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
    [robot.yaml]
2026-08-02 fix: シグナルでモーターを確実に解放する + 前進前の前方確認
    実機でモーターが回り続けたまま制御を失った。timeout の SIGTERM や Ctrl-C の既定
    動作では with の後始末 (hard_hiz) が走らず、L6470 が最後の Run 指令のまま回り続ける。
    ESC を押しても止まらない (これらのスクリプトはキー入力を読んでいない)。
    - motion/emergency_stop.py: シグナルハンドラで先に解放 (soft_stop -> hard_hiz) して
    から既定動作に戻して再送する。走行スクリプト (search_run / wall_survey /
    cell_move_demo) に組み込んだ。SIGKILL は捕捉できないので、その場合は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
    [cell_move_demo.py, motor_stop.py, search_run.py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]
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2026-08-11 fix: 木の床環境で右壁上面の色相ずれを拾えるよう h2_lo を広げる
    5x5 移行 (#65) のゲート確認で、右壁上面の色相が場所によって H=141-155 まで
    マゼンタ側へずれ、h2_lo=160 の外に出て帯の上 2/3 を取りこぼしていた (赤割合 0.155)。
    旧環境 (#56) は白飛び=彩度の問題だったが、木の床では露出が絞られて彩度は戻り
    (S=94-190)、今度は色相の問題に変わった。
    h2_lo を 160 -> 140 に広げる。右帯は 0.155 -> 0.442 で飽和し、木の床 (H=30-66,
    S=10-23) の漏れはゼロ、機体領域で新たに拾う画素も 0.6% のみ (青配線は H≈120 で
    余裕あり)。ゲー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
    [wall_detect.py]
2026-08-11 fix: wall_survey の無駄旋回を排除し、前進直前に位置補正を入れる
    5x5 木の床環境 (#65) の survey 中に機体が壁に接触し、自立壁 (床の差し込みが無い)
    が倒れた。旧環境なら無害だった「かすり接触」が、新環境では走行不能になる。
    接触の機会を減らす 2 つの修正:
    - 撮影後に元の向きへ戻す旋回を廃止。4 向き撮影の終了時の向きから、次の移動方向へ
    quarter_turns で直接回る (ツアーの Step.turn は使わず実際の向きから再計算)。
    1 セルあたり最大 2 旋回の削減 = 5x5 で約 30-50 旋回分の滑りと時間を節約
    - 前進の直前に 1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
    [wall_survey.py]
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2026-08-11 fix: ケーブルの偽帯を排除し、位置測定に確信度ゲートとゼロ点校正を入れる
    手動 survey (survey_shot) のデータで、自律走行時の「旋回しながら壁へ突進」の
    原因が確定した (#65)。3 点を修正する。
    1. BACK ROI をケーブルの通らない回廊 (x 262-352) へ移す。リボンケーブル (オレンジ
    H=7-9) は柔軟で写る位置が動き、x 215-260 / 360-440 に出る。帯探索が ROI を
    機体側へ ±40px 滑らせるためケーブルが窓に入り、幻の壁 (0.09-0.12) と偽の
    前後オフセット (-24mm) を作っていた。(3,0)E で 3 枚連続再現 → 修正後 0.001-0.024。
    2. cell_offs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
    [wall_detect.py]
2026-08-11 fix: BACK に辺別しきい値 0.25 を導入 (ケーブル偽帯との完全分離)
    ケーブルを避けて BACK ROI を移した (前コミット) が、フェーズB の (0,0)S で回廊内
    にもケーブルが写り込み、幻の壁 0.10-0.12 が再発した。ケーブルは柔軟で写る位置が
    動くため、固定の「安全な場所」は存在しないと結論。
    発想を変え、辺別のしきい値で分離する。5x5 手動調査の全 113 枚 = 452 ラベルで、
    BACK はケーブルの偽帯が最大 0.121、実壁の帯は太く写るため最小 0.509 と、分布が
    完全に分かれている。BACK のみしきい値 0.25 (他の 3 辺は 0.08 のまま)。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
    [search_run.py, survey_shot.py, wall_detect.py]
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2026-08-11 M5: 最速ラン + 走行の状態機械 (10分・5走の予算管理)
    待機 -> 探索 -> 復帰 -> 最速 -> ... を差配する RunManager を追加する (#20)。
    - 「走行」はスタート区画からゴールを目指す出発と数える (探索が 1 走目、復帰は
    数えない)。クラシック競技の 10 分・最大 5 走を管理する
    - 次の走行を始めるのは、残り時間が (復帰 + 最速) の見積もり x 安全率に足りる
    ときだけ。見積もりは実測の 1 セル 1.75s / 90° 1.64s (#17)。途中で時間切れに
    なるより、確実に完走できる走行だけを始める
    - 復帰・最速の経路は shortest_path (known=visited、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
    [speed_run.py]
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2026-08-14 M5: 筐体改修に伴う全面再校正 + カメラによる方位の絶対補正
    モータドライバを壁より高い位置へ移し、ホイール配置とカメラの高さ・傾きを変更した
    筐体改修に合わせて、カメラ幾何・運動学・ジャイロを測り直した。あわせて、今回の
    実機走行で露呈した「方位がどこにも固定されていない」問題を塞ぐ。
    カメラ幾何 (定規でセル中央に置いた 2 姿勢から実測):
    - CALIBRATED_BANDS / calibrated_rois を更新。px/mm は X 1.586->1.694 / Y 1.614->1.697
    (カメラが約 5% 低い)。改修前は X と Y が 1.8% 食い違っていたが、傾き修正後は
    0.2%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
    [robot.yaml]
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2026-08-14 hardware: 筐体再設計に合わせてプレートの配置を直し、三面図を再生成する
    e2168e0 で chassis の Z が 0〜56 から -47.000〜7.000 に変わったが、
    middle-plate と roof の Body.Placement が前設計の値のままだった。
    chassis↔middle-plate に 51.5mm の隙間、middle-plate↔roof に干渉 159.85 が
    残っていたので、取付穴の一致から配置を導出し直した。
    配置:
    | 部品 | Position (x, y, z) | Angle | 占有 Z |
    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
    [krilly-middle-plate-Body.stl, krilly-middle-plate.FCStd, krilly-roof-Body.stl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]
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2026-08-15 M6 #21: クラブ走行の残り (+1.30°) を wheel_angles_deg に反映する
    M5 の測り方は「置いたときの傾き」と「機体側のクラブ」を分離していなかったため
    -1.72° と過大に補正していた。正しくは
    横流れ = 720mm * sin(置いた傾き + 走行中の回転/2 + クラブ角)
    で、置いた傾きは axis_yaw の before、走行中の回転はカメラの前後差から取れる。
    4 セル直進 4 本 (v=0.12/0.18/0.24/0.30) で差し引くとクラブ角は
    +1.34/+1.53/+0.98/+1.36° と揃うので (平均 +1.30°、幅 0.55°)、config を
    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
    [robot.yaml]
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2026-08-15 M6 #21: ガタの帯の内側の残差はやり直さない (待つのではなく諦める)
    前のコミットの「揺れ戻りを残量と誤読している」という仮説は実機で外れた。揺れ待ちを
    0.25s 入れても**やり直しは 12/12 回そのまま発生**し、旋回時間は 1.71/1.66/1.86s から
    2.21/2.19/2.25s へ悪化しただけだった。
    残差を見ると理由が分かる。待った後でも |残差| は 0.9-1.45° で必ず残り、角速度を
    変えても同じ大きさになる。往復して 0 に戻る振動ではなく、**機体がガタの帯 (1.6-2°、
    issue #72) のどこかに落ち着いてそこに留まる**。だから待っても消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
2026-08-16 M6 #72: W0 のハブの緩みを直し、クラブ角を測り直す
    前輪 W0 の六角ハブのネジが緩んでいた。締めた後の実測 (5 フレーム平均):
    励磁の跳ね +2.06° -> -0.03 ± 0.26° (ゼロと区別がつかない)
    **#21 で「ローラーの遊びが精度の下限を決める、制御では詰められない」と書いたのは
    誤りだった。** 数字はローラーのクリアランスの計算とよく合っていたが、実際は緩んだ
    締結だった。旋回の残差 (1.04-1.40°) と行き過ぎ (2.3-3.2°) は締めた後も変わらないので、
    あれは遊びではない (#73 のジャイロの遅れが本命)。
    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
    [robot.yaml]
2026-08-16 M6 #72: クラブ角を -1.49° に決める (2 点の実測から外挿)
    W0 の締結を直したことで測定が再現するようになり、2 つの config で 2 本ずつ測れた:
    config -0.42 -> クラブ角 -1.583 / -1.537° (幅 0.046)
    config -1.20 -> クラブ角 -0.410 / -0.425° (幅 0.015)
    傾きは -1.46。理論の -1 と合わないのは、三輪の取付角の誤差が一様な回転ではなく輪ごとに
    違うためと思われる。外挿すると δ=0 は -1.485 なので -1.49 を採る。移動量が 0.29° と
    小さいので、傾きを -1 / -1.46 / -2 のどれで仮定しても残るクラブ角は -0.13 〜 +0.16° に
    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
    [robot.yaml]
2026-08-16 M6 #72: クラブ角の校正を締め、測定の雑音の底を記録する
    config -1.49 での実測 (4 セル直進 2 本): クラブ角 -0.586 / +0.137° = **-0.22 ± 0.17°**
    でゼロと区別がつかない。4 セルの実移動は定規で 720 / 723mm (指令 720mm)、カメラでも
    +3.5 / 0.0mm なので wheel_diameter_m は据え置き。クラブ補正はここで打ち止め。
    前のコミットに書いた「スポーク角を変えると前進のスケールも動く」は取り下げる。理屈は
    成り立つが (W1/W2 の指令が 0.8% 非対称に変わる、最大 5.8mm)、実測は単調でなく
    (config -0.42/-1.20/-1.49 で前後誤差 +2 / -10.6 / +1.8mm) 支持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
    [robot.yaml]
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2026-08-16 M6 #76 Phase 2: 経路と探索の表現を「旋回量」から「進行方角」へ変える
    離散層 (Explorer / shortest_path / RunManager) を、旋回する走り方と旋回レス走行の
    両方を表現できる形にした。実機の挙動は変えていない (スクリプトは holonomic=False で
    従来どおり旋回して走る)。
    **Step.turn / Leg.turn を削除し direction だけにした。** 同じ名前で「機体の旋回量」と
    「進行軸の変更量」の両方を表すと、走り方を混ぜたときに符号は合うのに意味が違うという
    最悪のバグになる。フィールドを消せば全呼び出し箇所が型エラーで落ちるので見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
    [search_run.py, speed_run.py, wall_survey.py]
2026-08-16 M6 #76 Phase 1b: 車輪ごとの実効径を持てるようにし、W0 を実測から入れる
    1x15 の通路で機体の置き方だけ変えて同じ距離を比べたところ (指令 720mm):
    前進 720 / 723mm (F4 x2)、1435/1440mm (F8) -> +0.02%
    横移動 718 / 731 / 728 / 734 / 725mm (H4 x5) -> **+1.00%**
    横だけ 1% 長い。前進とのスケール差 0.98% は Phase 1 の受け入れ基準 (1%) に達したので
    車輪別径へ進む。
    **前進と横移動では駆動する車輪が違う。** 逆運動学の係数は
    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
    [robot.yaml]
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2026-08-27 M6 #73: #81 の後に測り直した。旋回の行き過ぎは別の遅れだった
    実機 (Q,Q,Q,Q、#81 の連続サンプル込み):
    dt=20ms ω=2.0 行き過ぎ 4.5° / 1 旋回 1.83s
    dt=10ms ω=2.0 行き過ぎ 3.75° / 1 旋回 1.55s
    dt=20ms ω=1.0 行き過ぎ 3.03° / 1 旋回 2.24s
    **#81 の修正は旋回には効いていない** (2.3-3.2° -> 4.5°)。同じ走行の A/B でも、
    旋回中は点サンプルと連続積分が 0.2° しか違わない (並進では 1.32° 対 0.009°)。
    旋回は角速度が大きくなめらかなので、エイリアスする速い成分がない。**#73 と #81 は
    同じ根本原因ではなかった。**
    当てはめると 行き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
2026-08-29 M6 #78: 赤マスクの色相下限を 140 -> 125 に広げる
    8x8 の探索ラン 1 回 (21 フレーム / 204 ラベル / 壁の帯 90 本) を後からラベル付け
    して測った結果、left の一番弱い壁が 0.092 = しきい値 0.08 の 1.1 倍しかなかった。
    #88 は 0.24 の壁を落として壁を突き破っている。ここが次に run を終わらせる場所。
    原因は帯の色相が h2_lo=140 の下へこぼれていたこと。h2_lo を振ると壁側だけが
    上がり、壁なし側は 120 まで 0.003 のまま動かない (115 で 0.010 へ漏れ始める):
    h2_lo 140 135 130 125 120 115
    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
    [run_labels.csv]
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2026-09-23 sim: 始点が競技の形 (北の 1 つだけ開く) かを検査し、生成・切り出しで直す (#127)
    - check.start_openings / check_maze: 始点の開口が [N] でなければ注意 (誤りにはしない。
    excerpt8 系・twisty8 は実験用の盤面)。--white-tops なら --no-seed-start が要ると案内
    - generate.competition_start: 北を開け他を閉じ、孤立したセルは始点以外の壁で繋ぎ直す
    - random_maze(fix_start=True) が既定で適用。twisty8 と #87 の安全率の試験は
    fix_start=False で従来の迷路を固定
    - excerpt.goal_variants も適用 (maze_excerpt の出力は始点が競技の形になる)
    - 書き起こした大会迷路 31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
2026-09-24 launcher: ボタン 1 個 + ブザーで機体単体で走らせる (#79)
    - hal/gpio_io: Button (内部プルアップ、押すと 0) / Buzzer (passive は PWM、active は H/L)。
    lgpio をフェイクに差し替えてテストできる形
    - app/launcher: 状態機械 (待機 / カウントダウン / 走行中 / 停止中 / 設定エラー / 電源断)。
    1 秒押して離すと 3 秒後に発進、走行中に押すと SIGINT、5 秒で電源断。
    停止は既存の emergency_stop を通る SIGINT だけで、SIGKILL は送らない
    (止まらなければ警報を鳴らし、VS 遮断のトグルに任せる)。長押し系のイベントは待機中に
    押し始めた押下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
    [gpio_io.py, launcher.py, speed_run.py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]
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2026-09-24 launcher: 鳴っていないブザーを止めると lgpio が例外を出す件を直す (#79)
    実機の --beep-test で最初の音の後にスレッドが死に、以後鳴らなかった。
    lgpio は動いていない PWM を止めると 'bad PWM micros' を出す (鳴らす前の off、
    2 回続けた off)。Buzzer が PWM の状態を持ち、音のスレッドは例外で死なないようにした。
    [gpio_io.py, launcher.py, test_gpio_io.py]
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2026-10-10 試走会と本番の振り返り: SPI の見張り、電源の手順、ログを残す設定
    - scripts/spi_watch.py: L6470 の STATUS を 20Hz で読み、応答なし / WRONG_CMD を数える。
    試走会の NO_SPI 中断を、配線を揺らして再現した (挿し直し後は 598 回とも正常)
    - venue-checklist: カメラが回ったかの確認 (向かい合う壁の一致では分からない)、
    SPI のコネクタの確認、電源の入れ方・切り方 (本番はここで起動できなかった)
    - setup-pi5 §9: POWER_OFF_ON_HALT=1、journald を persistent に、時刻と RTC
    - CLAUDE.md: 試走会 (16x16 完走、最速 63.3s / 見積 63.0s) と本番の失敗の記録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
2026-10-16 fix: 走行中に SPI が途切れたら回復せずに打ち切り、ランチャが警報を鳴らす (#148)
    2026-10-16 の 8x8 で 3 台とも NO_SPI になったのを、回復 (#113) が「原因不明の
    回転」として扱って次の区間を指令し、届かない指令のまま機体がさらに 16° 回った。
    - hal.l6470: dead_devices() / SpiLost を追加
    - L6470Chain.release_until_alive(): 応答が戻るまで HardHiZ を送り続ける
    (接触不良は途切れては戻るので、戻った瞬間に解放を届ける)
    - motion.tuning.raise_if_spi_lost(): 動作後の STATUS で応答なしなら解放して SpiLost
    - app.exit_codes: EXIT_ABORTED (2) / EXIT_SPI_LOST (3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
2026-10-16 fix: 解放が届いたかは応答が無いと分からないので、文言を「確認できない」にする (#148)
    実機確認 (STATUS の読みだけを 0x0000 にすり替え) では、すり替える前の本物の STATUS が
    0x7E12 -> 0x7E13 (HiZ ビットが立つ) に変わり、解放は届いていた。
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2026-11-08 fix: 軸角の補正を推定方位との差で判定し、迷路の軸から外れた線分を捨てる (#152)
    2026-10-17 の会場で、閉じたマスに斜めに立てかけた余りの壁が写り、軸角が +5.76° /
    +4.39° と読まれ、+4.39° は 5° のガードを通って機体を 4.4° 傾けた。
    - axis_yaw: 最も線分が集まる角度 (最頻) から inlier_deg = 5° 以上離れた線分を捨ててから
    平均する。会場の画像は +5.76° -> +0.09° (軸外の 1059px を捨てる)。AxisYaw に
    rejected_length_px を追加
    - grid: MAX_HEADING_CORRECTION_RUNNING_RAD = 3°。speed_run / search_run は最初の
    方位補正が通った後はこれを使う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
2026-11-08 fix: コーナー減速の分を走行時間の見積もりに入れる (corner_time_s 0.24s、#154)
    コーナー減速 (#150) で繋いだ動作が長くなったのに、見積もりは減速前の定数のままで
    最速ランを 7% 短く見積もっていた (「終われない走行を始める」側の誤り)。
    - RunManager.corner_time_s = 0.24s をまとまり内のコーナー (継ぎ目) ごとに足す。
    同じ 8x8・同じ経路の対で測った: chain2 (コーナー 1 回) 56 本の平均 2.13s -> 2.37s
    - 8x8 の最速ラン (8 動作 / コーナー 7 回): 見積 20.00 -> 21.68s、実測 21.55s (+0.6%)
    - 大会迷路 30 面: 最速 0 本の面 3/30 のまま、最速ラ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
2026-11-08 fix: 動作の最中の上限を終わった後の残差 (2.5°) と分け、既定 4.0° にする (#153)
    8x8 の実機 (84 動作) で、正常な動作の最中の向きのずれは最大 2.19° (コーナーの最中、
    終わった時点では 0.2°)。2.5° では余裕が 0.3° しかなく、正常な動作を接触と取り違え
    かねない。--max-heading-in-motion (既定 4.0°) を追加。実際の接触は 5.0-28° で、
    2.5-4° の軽い接触は終わった後のガードが捕まえる。
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2026-11-08 hardware: 中継基板に合わせて筐体を修正する
2026-11-08 fix: 壁の帯の位置を、ROI の赤割合最大ではなく半値幅の中点で読む (#156)
    帯がセル内側へ薄い裾 (割合 0.1-0.4) を引くと、赤割合が最大の ROI 位置 (平坦部の中心)
    がその側へ引っ張られ、向かい合う壁の読みが食い違っていた。BACK を 114mm に広げた
    PR #155 の後は、同じ効果で BACK が約 -7mm ずれ、前後が 7-8mm 食い違っていた。
    - best_roi_red_fraction: 位置は「ROI 内の最大値を含む帯の半値幅の中点」で読む。
    帯が探索窓の端まで続くなら飽和。赤割合 (壁の有無) は従来どおり ROI の最大値。
    search_px=0 (固定 ROI) では従来どお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
2026-11-09 hardware: ステッピングモータ・ハブ・オムニホイールのモデルと組立図を追加する
    - SS2421-5041（□42 薄型・片軸）の外形モデル。寸法はカタログ p.44 の外形図、
    取付用 M3 タップは軸側から見て右上・左下の 2 か所（実物で確認）
    - ヴイストンの φ48 オムニホイールと φ5 軸用 六角ハブ S12。ローラー寸法と
    六角穴の深さ 10.5 は実測、ハブは底の輪に突き当てて反対側から M4 で締める
    - krilly-assembly.FCStd: シャーシにモータ・ハブ・ホイールを 3 組取り付けた
    Assembly。部品は App::Link 参照なので元の FCStd の修正がそのまま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
